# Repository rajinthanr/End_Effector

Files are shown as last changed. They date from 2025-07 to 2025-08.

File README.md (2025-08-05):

# Reconfigurable End Effector for Robotic Depalletizing



This repository documents the design and development of a flexible robotic end effector system, engineered to automate depalletizing operations in supermarket warehouses. The design emphasizes inclusive design principles, sensor-driven adaptability, and seamless mechanical-electronic integration.

---

## 📁 Table of Contents
1. [Project Overview](#project-overview)  
2. [Inclusive Design Framework](#inclusive-design-framework)  
3. [Market Research & Reference Design](#market-research--reference-design)  
4. [Conceptual Development](#conceptual-development)  
5. [Component Selection](#component-selection)  
6. [Mechanical Design](#mechanical-design)  
7. [Electronic Design](#electronic-design)  
8. [Firmware Development](#firmware-development)  
9. [Project Files](#project-files)  
10. [Team Members](#team-members)

---

## 🧠 Project Overview

This project aims to develop a **reconfigurable robotic end effector** capable of handling various box sizes and weights using vacuum-based gripping and pneumatic actuation. Key technologies include:

- **Time-of-Flight (ToF) sensors** for angular alignment  
- **Vacuum suction cups** for box lifting  
- **Pneumatic cylinders** for stabilization  
- **ATmega2560-based controller** with real-time firmware  

The end effector is compatible with standard robotic arms and designed for integration into warehouse logistics systems.

---

## 🌟 Inclusive Design Framework

We initiated this project using the [**Inclusive Design Toolkit**](https://www.inclusivedesigntoolkit.com/) by the University of Cambridge.

### 👥 Stakeholder Mapping
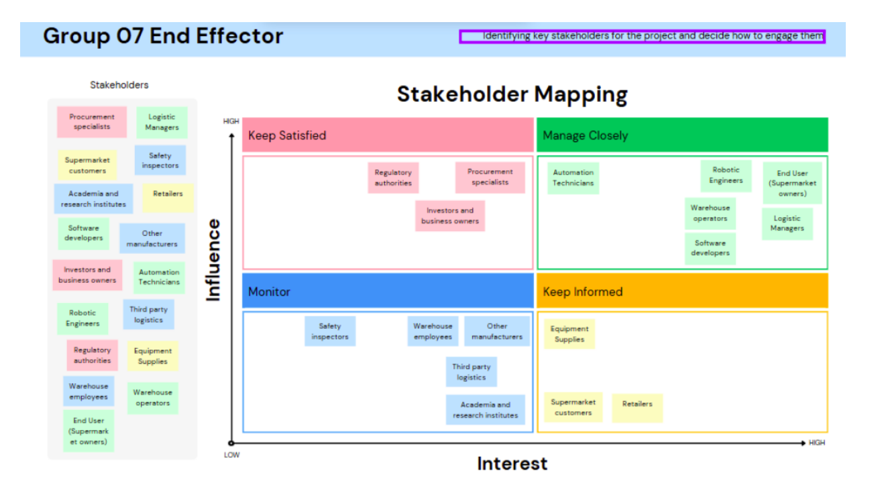
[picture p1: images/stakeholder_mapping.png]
Stakeholder Mapping


We categorized stakeholders into groups based on interest and influence to ensure inclusivity across the design lifecycle.

### 📌 User Needs Identified
- Automatic adaptation to box size and surface
- Safe handling of fragile or irregular packages
- Integration with existing robotic systems
- Minimal maintenance with reliable performance

---

## 🔍 Market Research & Reference Design

Before prototyping, we analyzed commercial solutions such as the **MCS-RP Gripper Series by WSR Solutions**, known for:
- Modular design
- High grip force
- Versatility in gripping geometry

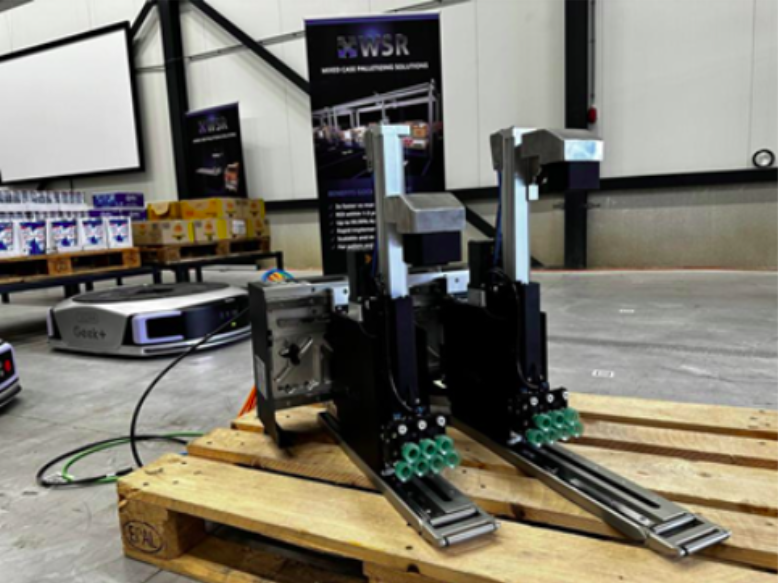
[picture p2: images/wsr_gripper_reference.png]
Reference Gripper


---

## ✍️ Conceptual Development

We iterated through several hand-drawn and CAD-based sketches to derive the optimal design.

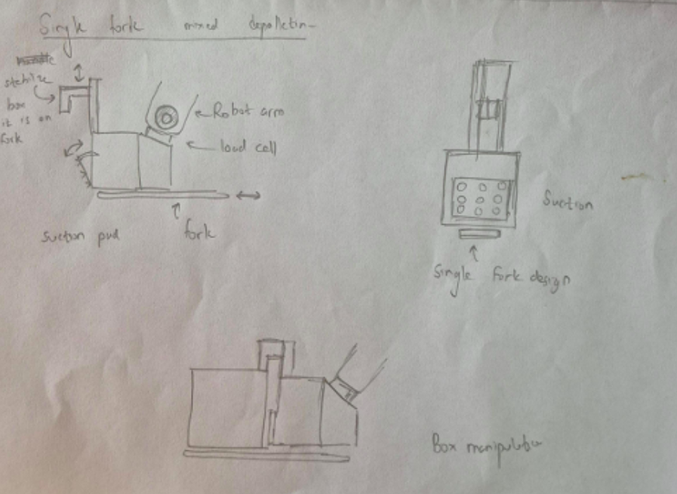
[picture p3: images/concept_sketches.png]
Conceptual Designs

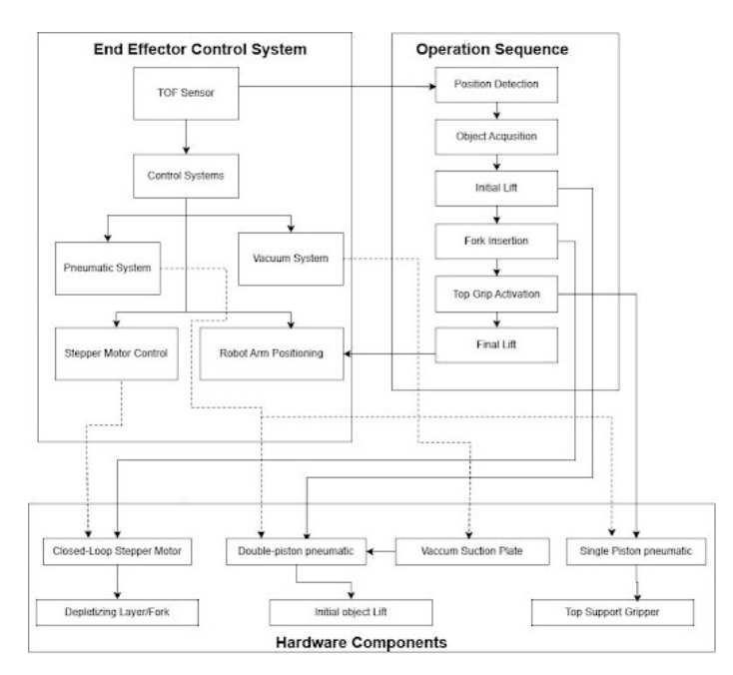
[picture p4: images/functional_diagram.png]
Functional_diagram


This included a **functional block diagram** illustrating the interaction between suction mechanisms, ToF sensors, solenoids, and microcontroller units.

---

## 🧹 Component Selection

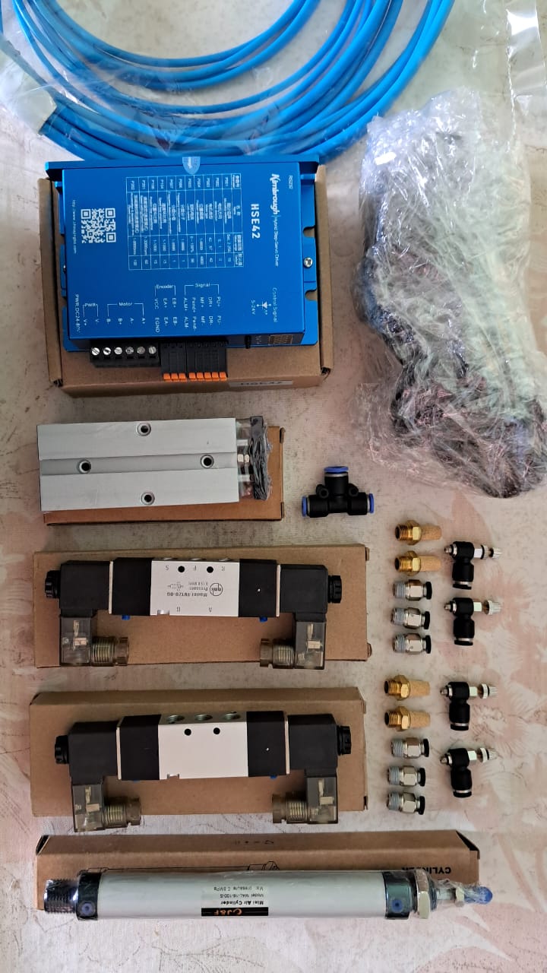
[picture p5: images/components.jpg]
Mechanical components


We conducted technical evaluations and cost analysis to select the following:

| Component | Model/Type | Reason |
|---|---|---|
| Stepper Motor | 42HSE47 Closed-loop | Precision & torque control |
| Pneumatic Cylinders | Airtac TN10X50 / MAL16X100 | Compact & cost-effective |
| Suction Cups | Schmalz FSG 20 NBE-ESD  | Adaptability to uneven surfaces |
| Vacuum Ejector | Airbest AZH10BS | Cost-efficient vacuum generation|
| Microcontroller | ATmega2560 | Multi-UART, reliable processing |

For more details about Tof sensor
https://support.nooploop.com/tofsense/protocol/

---

## 🛠️ Mechanical Design

### SolidWorks Iterations:
1. **First iteration**: Focused on confirming dimensions and fit.
2. **Final enclosure**: Zinc-coated sheet metal for durability and optimized integration with electronics.

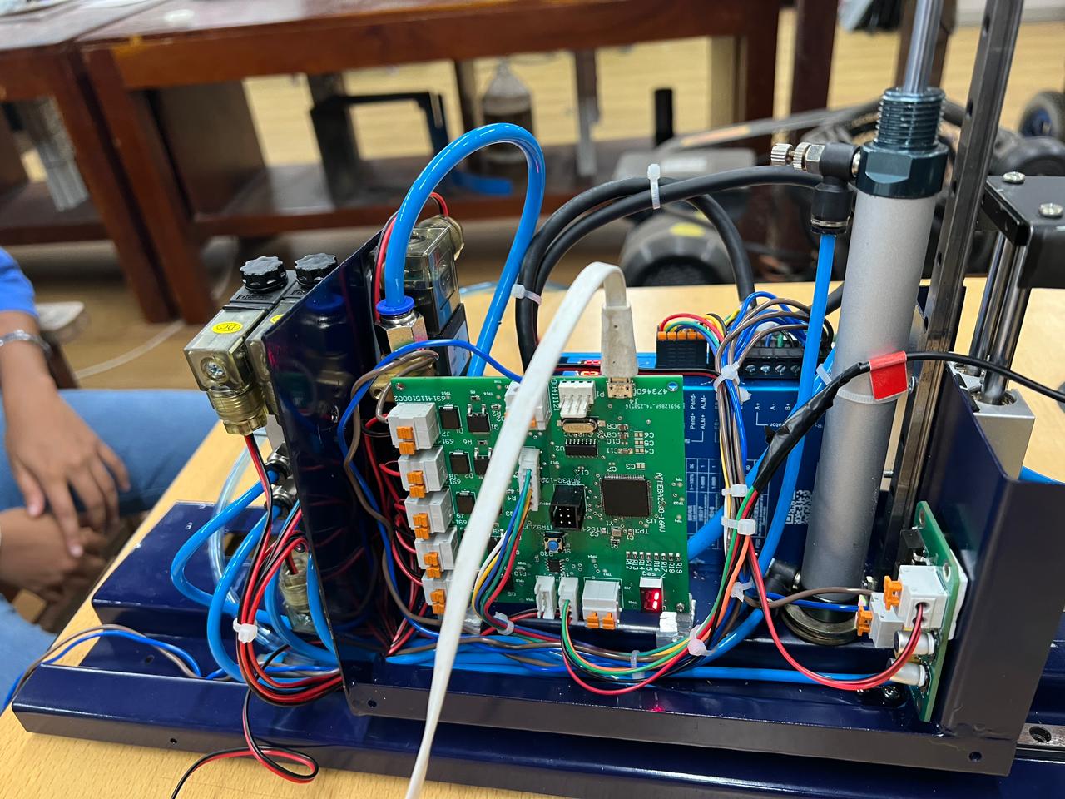
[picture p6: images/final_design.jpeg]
Final Mechanical Design


---

## 🔌 Electronic Design

We designed a **hierarchical schematic** in Altium Designer and manufactured the PCBs via JLCPCB.

### 📀 PCB Highlights:
- 2-layer main control PCB  
- Separate buck converter PCB for power regulation  
- RS485, UART, and SPI interfaces  
- Solenoid switching circuitry with flyback protection

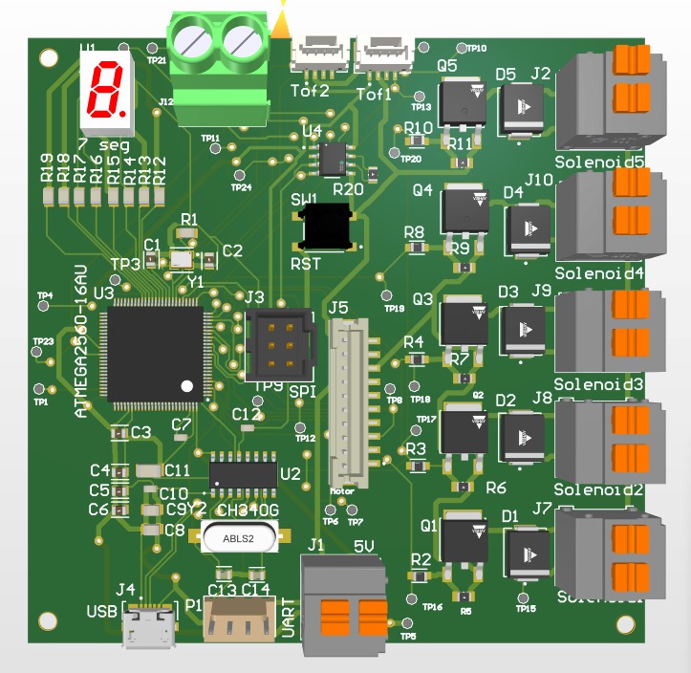
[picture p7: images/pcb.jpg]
PCB


> ⚙️ PCB and schematic files are included in the `/hardware` directory.

---

## 💻 Firmware Development

The firmware was developed using **Atmel Studio** and **register-level programming** for ATmega2560. Key features include:

- Multi-UART communication with ToF sensors
- Real-time control of vacuum, solenoids, and motors
- Serial communication with host controller (RS485)
- Modular codebase with functional headers and drivers

> Firmware source can be found under the `/firmware` folder.

---

## 📂 Project Files

| Folder | Description |
|---|---|
| `/firmware` | Register-level code for ATmega2560 |
| `/hardware` | Altium schematics, PCB, and BOM |
| `/cad` | SolidWorks files and STL exports |
| `/images` | Diagrams and renders used in this repository |
| `/docs` | Full project report and datasheets |

---

## 👨‍💻 Team Members

- Muftee M. M. M.  
- Goonetilleke P.  
- Jayakody J. A. K.  
- Rajinthan R.
- Warushavithana N. D.  
- Praveen V. V. J.  
- V. G. V. Gunasekara  

---

## 📜 License

This project is licensed under the MIT License – see the [LICENSE](LICENSE) file for details.

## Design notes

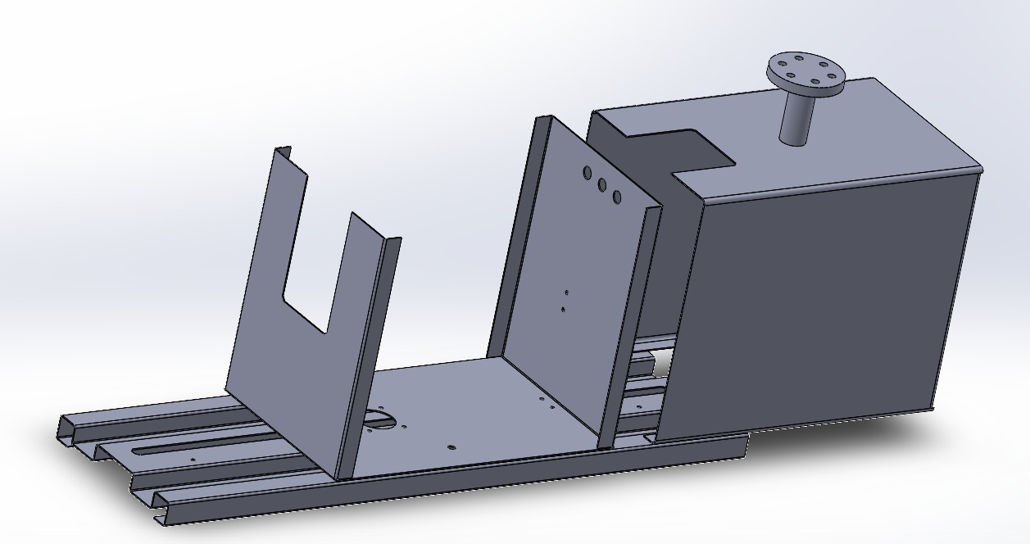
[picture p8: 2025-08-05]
images/enclosure.jpg

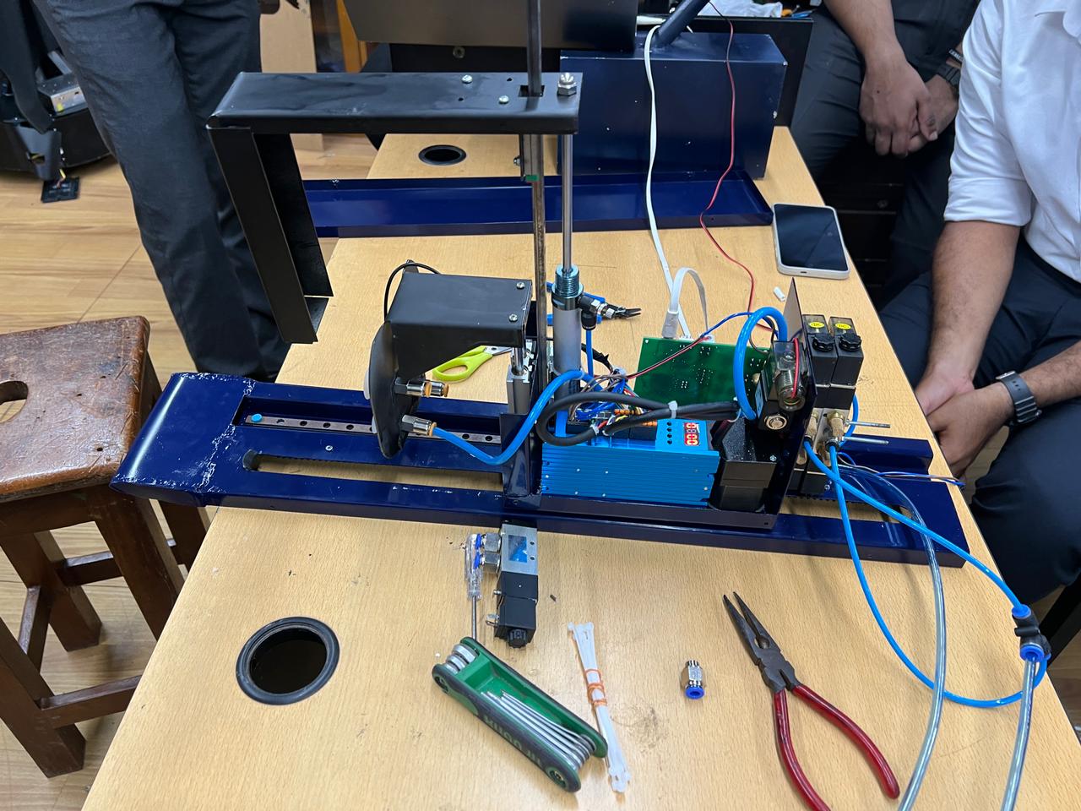
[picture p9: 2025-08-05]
images/end_effector.jpeg

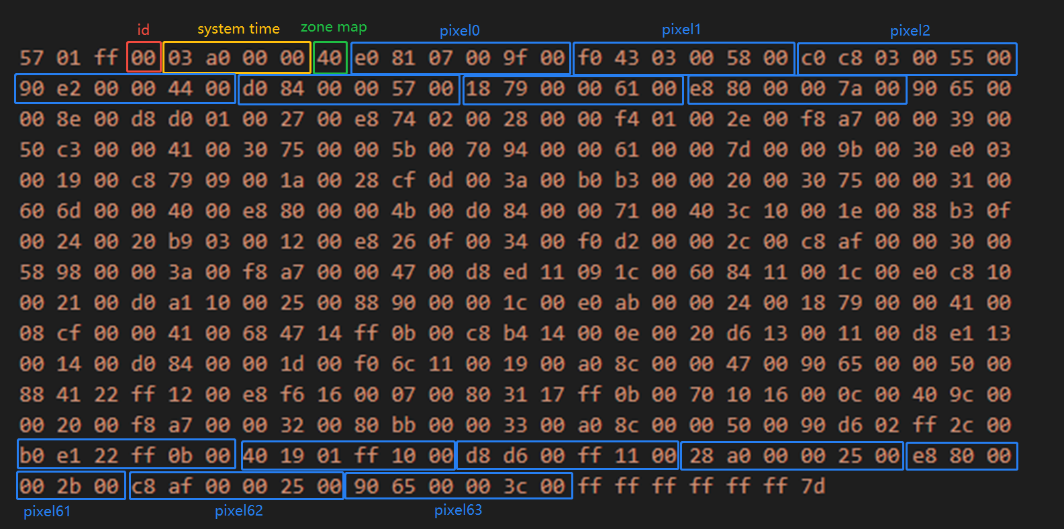
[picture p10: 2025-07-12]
firmware/TOFSense_M_unpack_demo.png

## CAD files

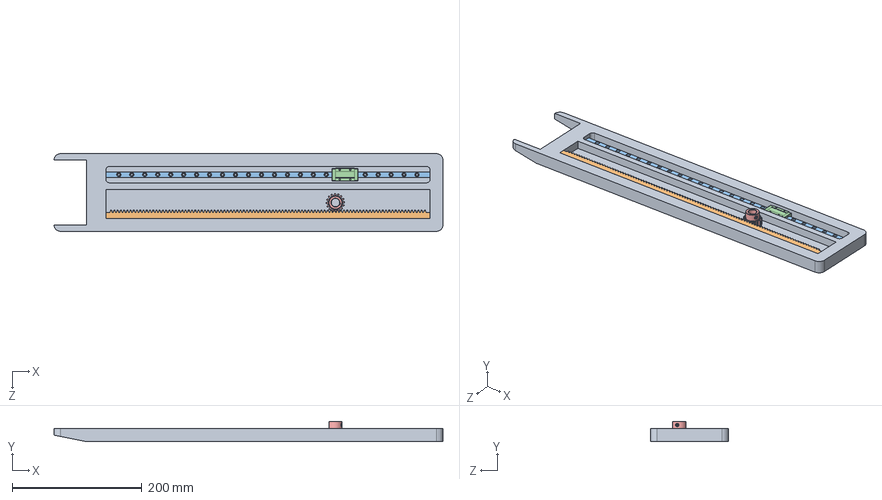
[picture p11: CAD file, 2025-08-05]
cad/Assembly.SLDASM
600.0 x 31.1 x 120.0 mm
fork
Rack
MGNR09_xxx
MGN09H

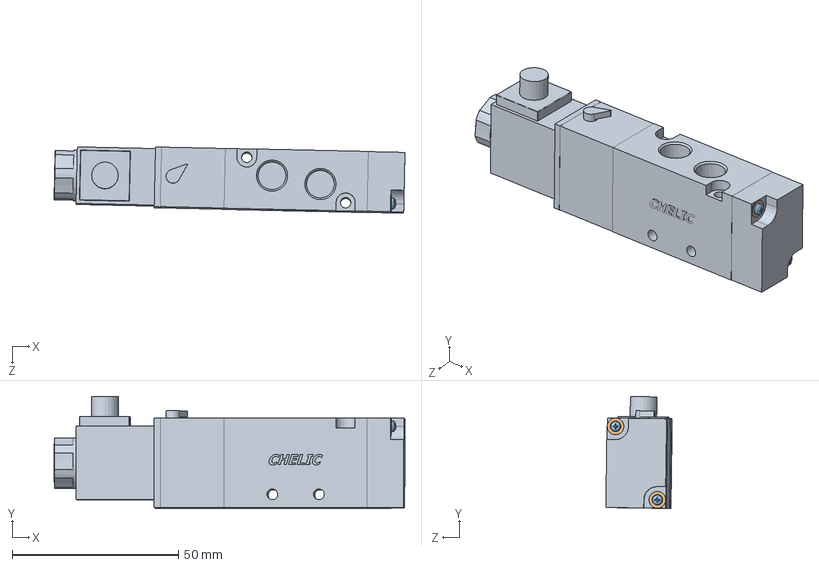
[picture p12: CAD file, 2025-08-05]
cad/Solenoid valve 52-18 Chelic.stp.SLDASM
105.5 x 33.7 x 20.0 mm
Solenoid valve 52-18 Chelic.stp
ISO 7091 - ST 2 - 100 HV.stp x 2
ISO 7045 - M1,6 x 3 - 4.8 - Z.stp x 2

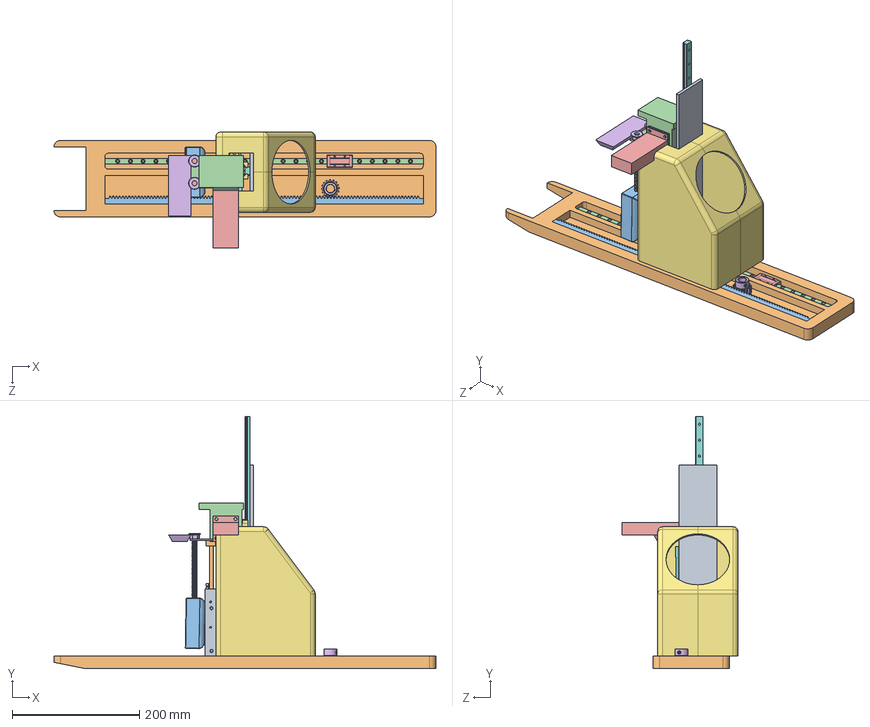
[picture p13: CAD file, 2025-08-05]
cad/vaccum-assembly.SLDASM
600.0 x 396.4 x 182.1 mm
CXSM10-50_cyl_cxs
CXSM10-50_pr_cxs
initial_enclosure
connector
rod x 2
nut x 2
161268 DZF-32-100-A-P-A---(ZR)
DIN-439-B - M10x1.25(F)
332223 DGP-25 x 2
161268 DZF-32-100-A-P-A---(KS)
main
arm_ex^Assem1
rubber
mov
rail
base
fork
Rack
MGNR09_xxx
MGN09H

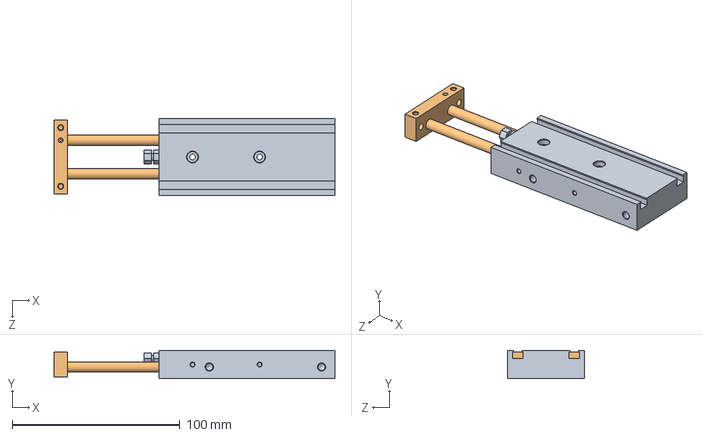
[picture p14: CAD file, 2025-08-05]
cad/5cmm pnum.SLDASM
167.6 x 17.0 x 46.0 mm
CXSM10-50_cyl_cxs
CXSM10-50_pr_cxs

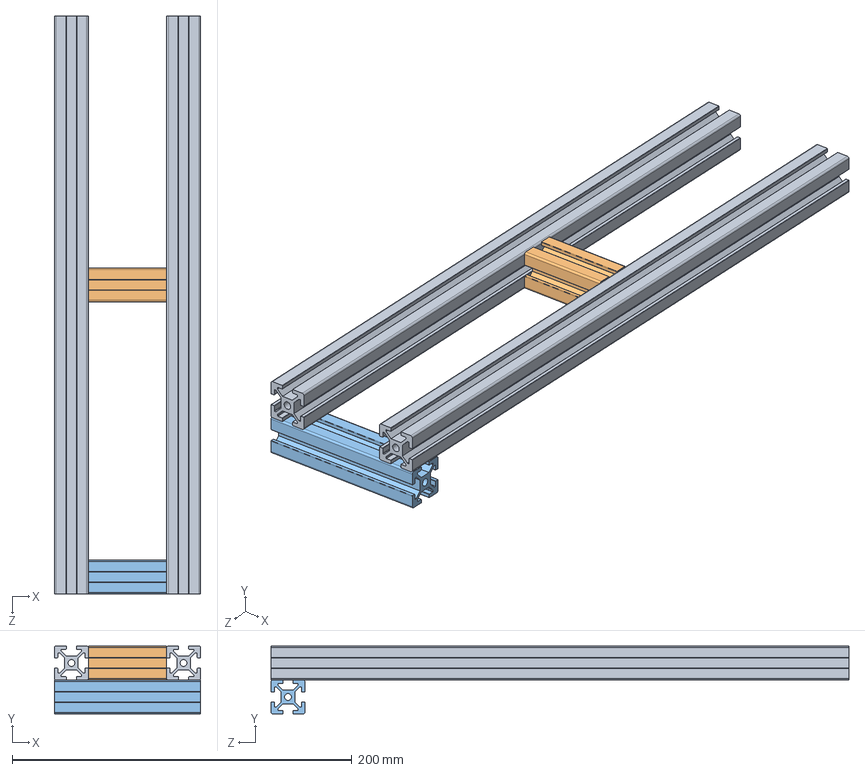
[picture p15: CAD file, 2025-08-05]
cad/Frame.SLDASM
86.0 x 40.0 x 340.0 mm
T slot 30 x 2
T slot hor 4c6
T slot hor 8c6

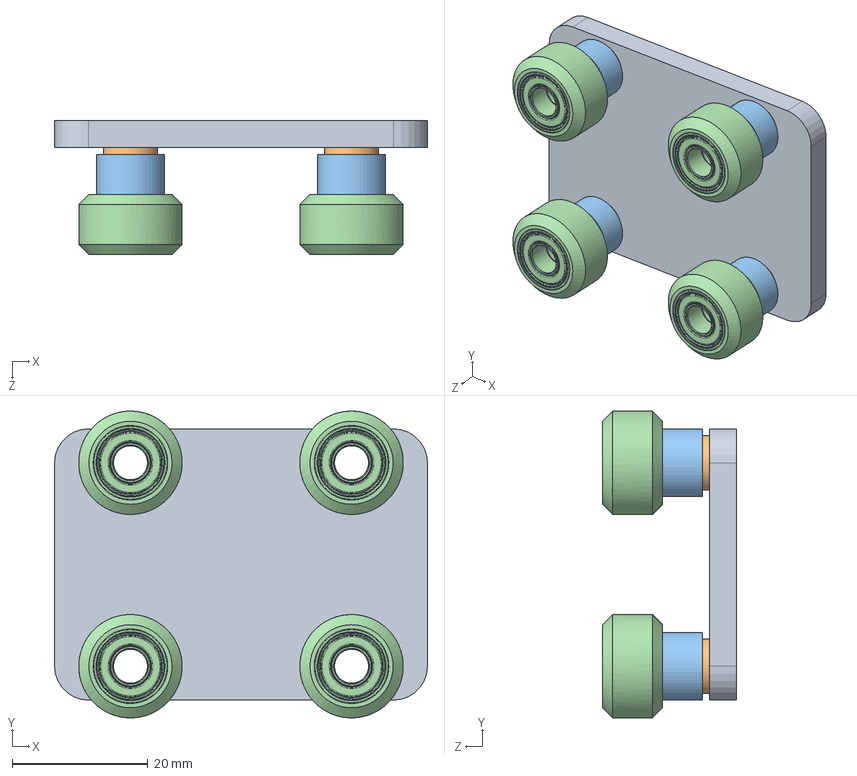
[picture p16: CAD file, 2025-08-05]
cad/vwheels.SLDASM
55.0 x 45.2 x 19.8 mm
spacer
MVG-P2 x 4
MVG-P3 x 4
MVG-P7 x 4

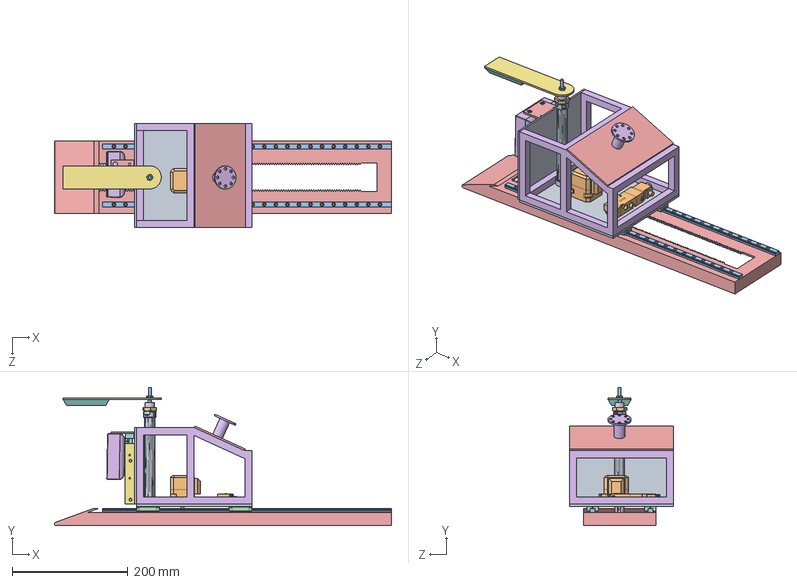
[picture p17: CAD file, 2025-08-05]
cad/Final.SLDASM
582.7 x 239.0 x 180.0 mm
botom plate
17HS08 stepper
MGNR09_xxx x 2
MGN09H x 4
rail plate
top box
CXSM10-50_cyl_cxs
CXSM10-50_pr_cxs
16 X 100 Cylinder bore
Nut 16
Rod
Nut 5
connector
initial_enclosure
top grpi stand
rubber
front cover
Solenoid valve 52-18 Chelic.stp
ISO 7091 - ST 2 - 100 HV.stp x 2
ISO 7045 - M1,6 x 3 - 4.8 - Z.stp x 2
top cover
arm connector circle

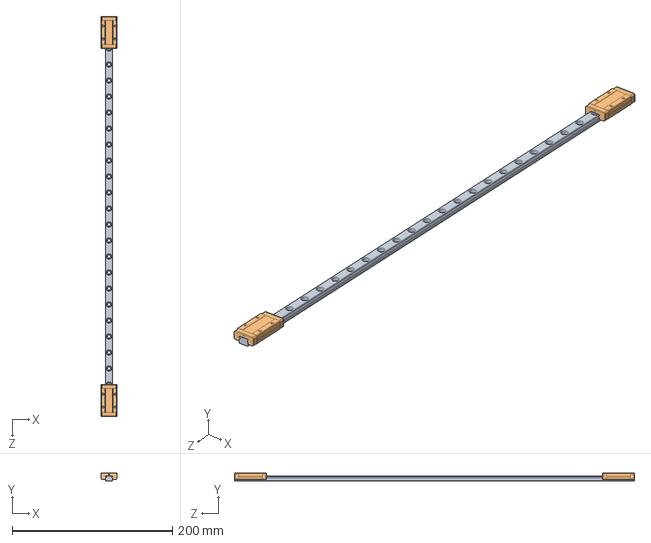
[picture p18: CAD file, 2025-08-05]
cad/MGN09.SLDASM
20.0 x 10.0 x 500.0 mm
MGNR09_xxx
MGN09H x 2

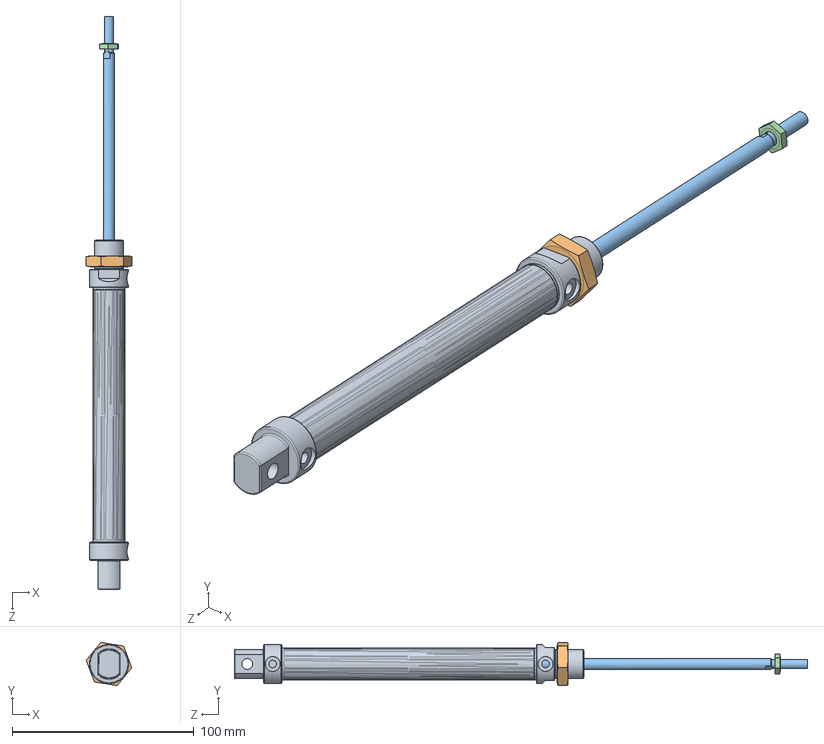
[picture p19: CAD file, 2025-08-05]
cad/16 X 100 Cylinder.SLDASM
25.1 x 23.8 x 315.0 mm
16 X 100 Cylinder bore
Nut 16
Rod
Nut 5

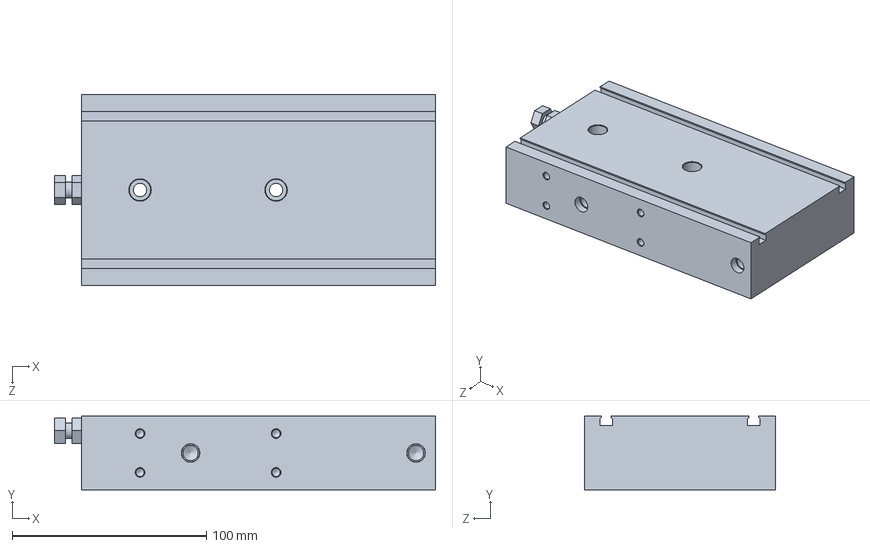
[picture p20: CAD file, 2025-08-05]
cad/CXSM10-50_cyl_cxs.sldprt
196.0 x 38.0 x 98.0 mm

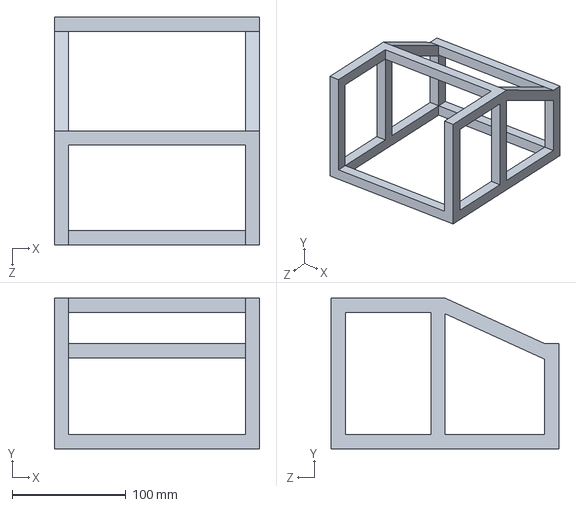
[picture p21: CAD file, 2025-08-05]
cad/top box.SLDPRT
180.0 x 132.5 x 200.0 mm

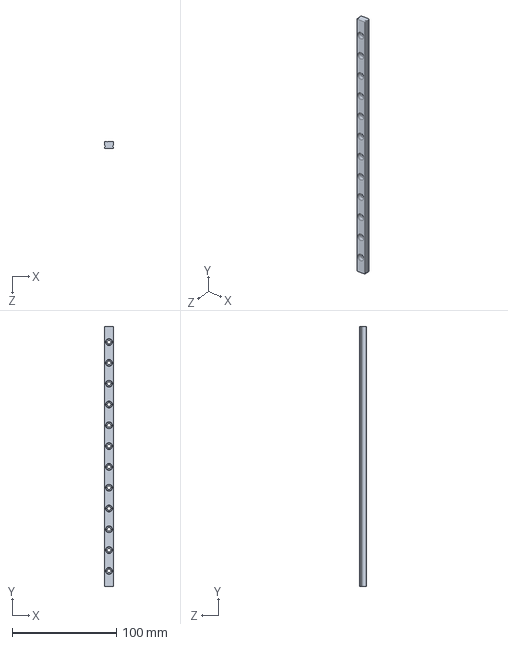
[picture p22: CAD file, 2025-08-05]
cad/MGNR09_xxx.SLDPRT
9.00 x 250.0 x 6.50 mm

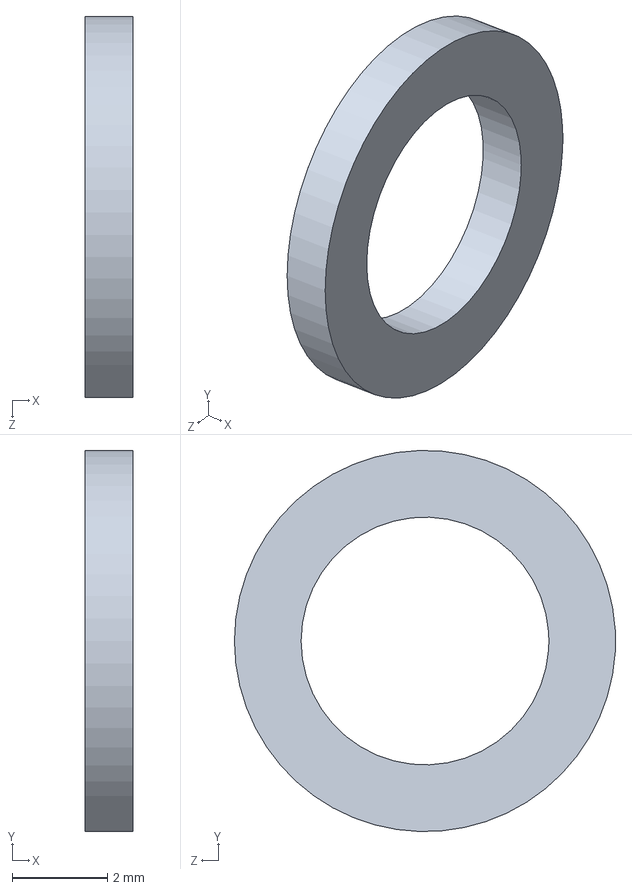
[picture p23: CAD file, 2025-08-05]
cad/MVG-P2.SLDPRT
1.00 x 8.00 x 8.00 mm

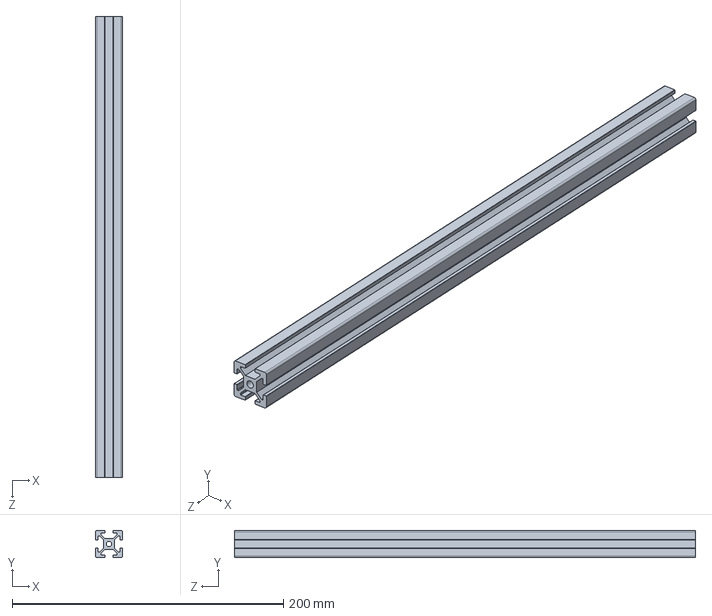
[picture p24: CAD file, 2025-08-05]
cad/T slot 30.SLDPRT
20.0 x 20.0 x 340.0 mm

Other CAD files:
cad/Rod.SLDPRT
cad/Gear.SLDPRT
cad/17HS08 stepper.SLDPRT
cad/top cover.SLDPRT
cad/16 X 100 Cylinder bore.SLDPRT
cad/161268 DZF-32-100-A-P-A---(0).SLDASM
cad/161268 DZF-32-100-A-P-A---(KS).SLDPRT
cad/161268 DZF-32-100-A-P-A---(ZR).SLDPRT
cad/332223 DGP-25.SLDPRT
cad/CXSM10-50_pr_cxs.sldprt
cad/DIN-439-B - M10x1.25(F).SLDPRT
cad/ISO 7045 - M1,6 x 3 - 4.8 - Z.stp.SLDPRT
cad/ISO 7091 - ST 2 - 100 HV.stp.SLDPRT
cad/MGN09H.SLDPRT
cad/MVG-P3.SLDPRT
cad/MVG-P7.SLDPRT
cad/Nut 16.SLDPRT
cad/Nut 5.SLDPRT
cad/Rack.SLDPRT
cad/Solenoid valve 52-18 Chelic.stp.SLDPRT
cad/T slot hor 4c6.SLDPRT
cad/T slot hor 8c6.SLDPRT
cad/arm connector circle.SLDPRT
cad/arm connector.SLDPRT
cad/botom plate.SLDPRT
cad/connector.SLDPRT
cad/fork.SLDPRT
cad/front cover.SLDPRT
cad/rail plate.SLDPRT
cad/rubber.SLDPRT
cad/spacer.SLDPRT
cad/top grpi stand.SLDPRT
cad/top hand.SLDPRT

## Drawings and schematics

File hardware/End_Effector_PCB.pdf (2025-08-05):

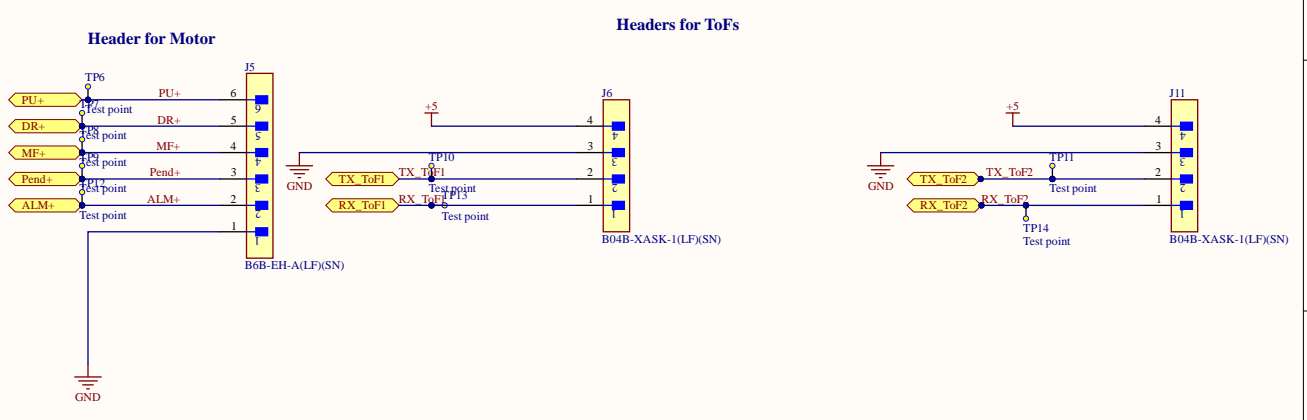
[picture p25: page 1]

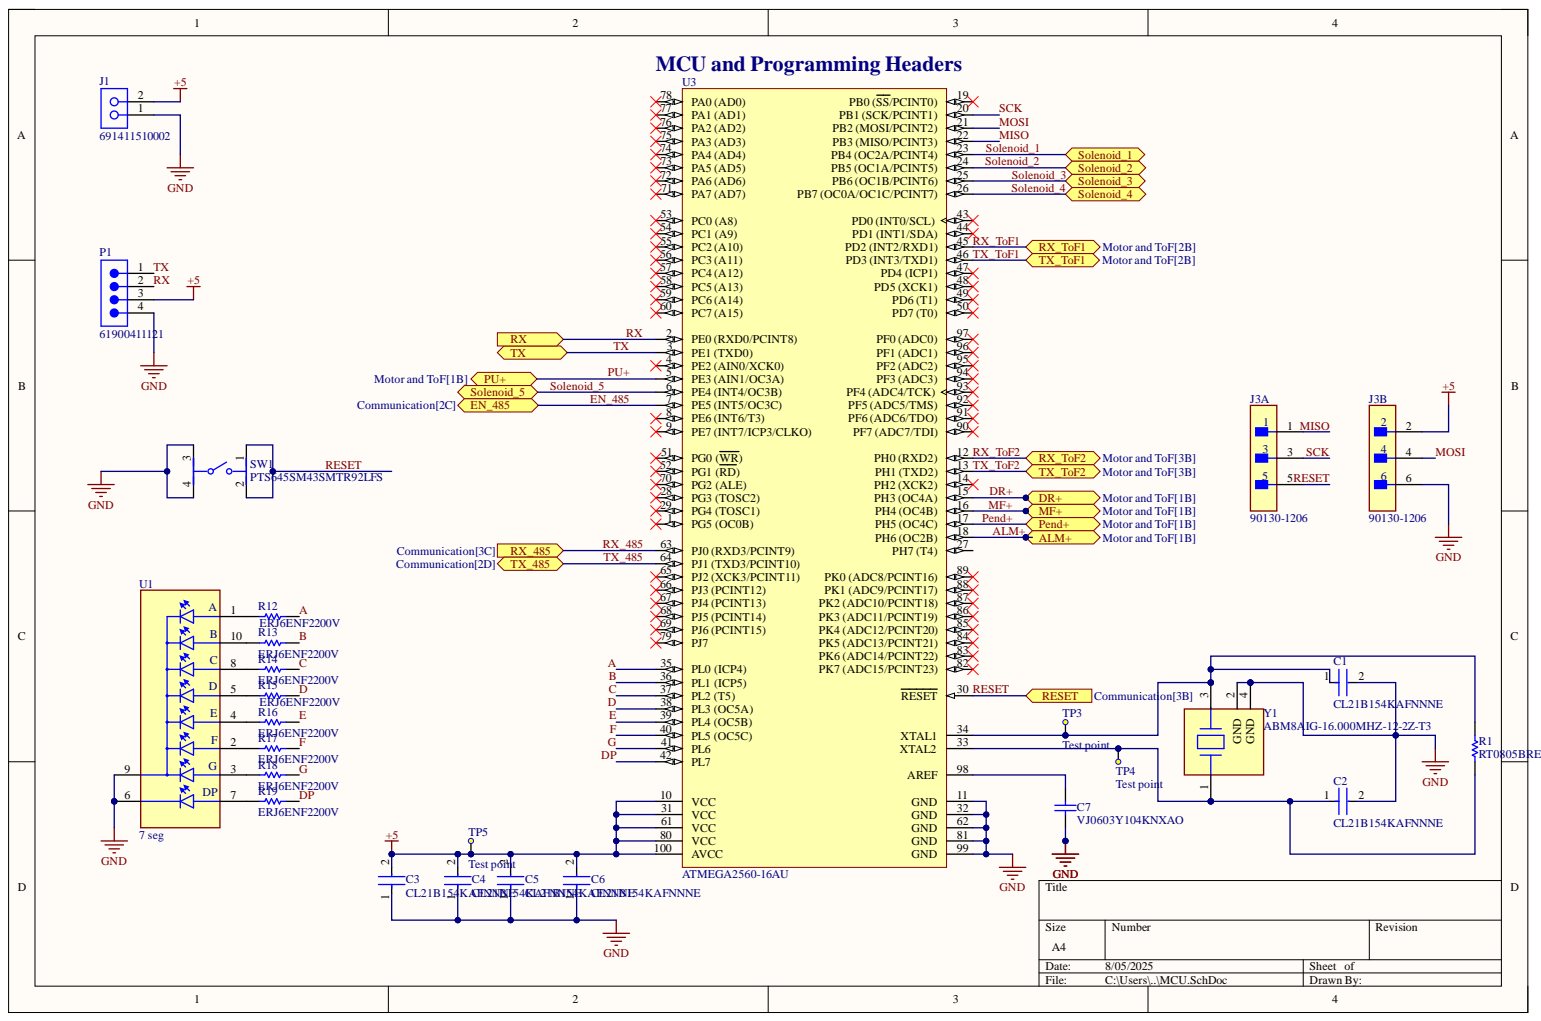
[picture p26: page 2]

3 1 | 3 2 | 2 1B1 5 4 K
6 1 | 6 2
8 0 | 8 1
1 0 0 | 9 9

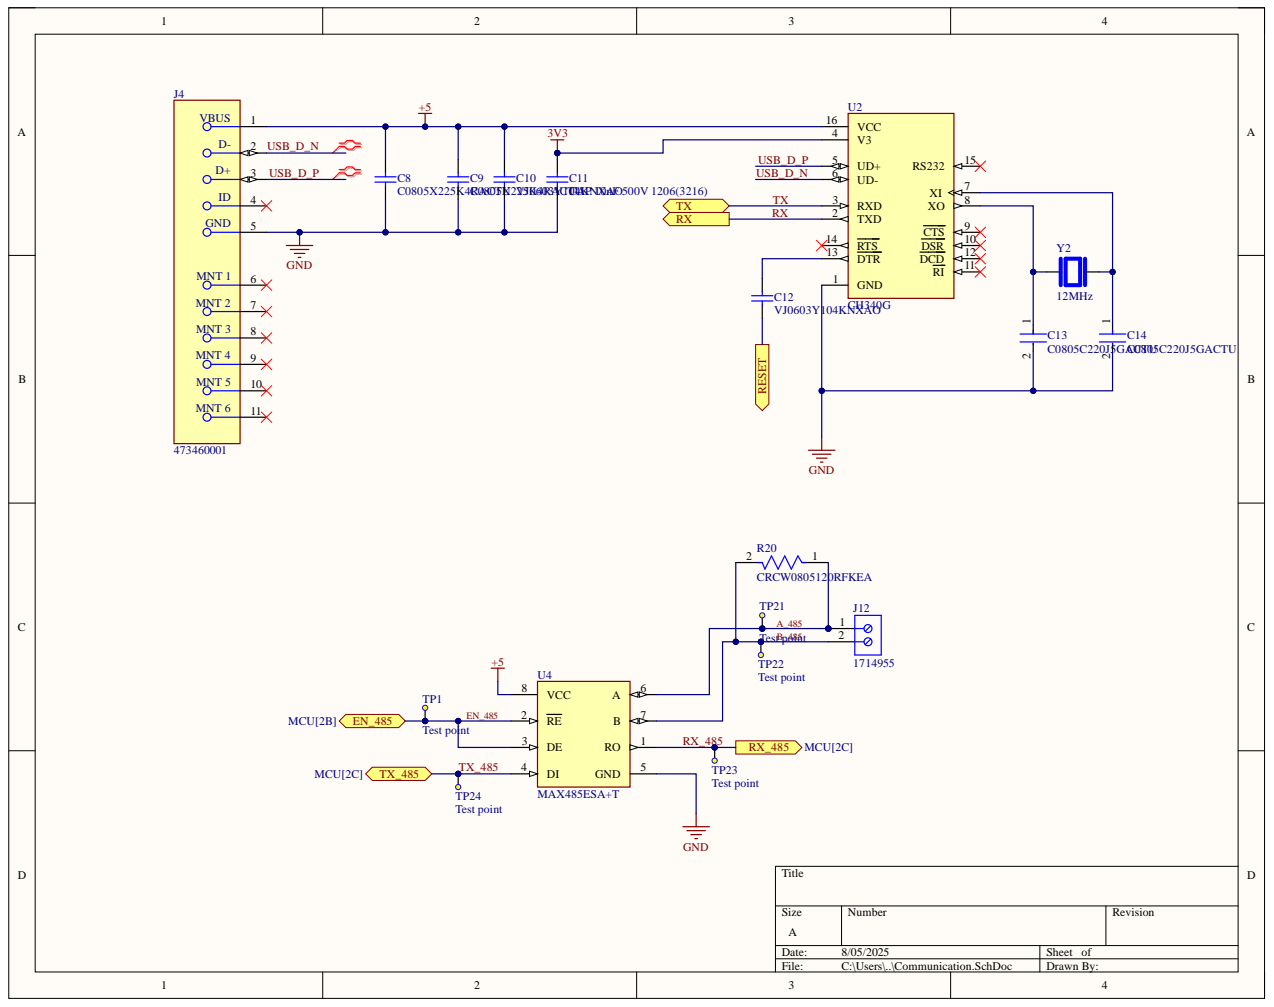
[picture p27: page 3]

Size A | Number | Revision

Date: 8/05/2025 | Sheet of
File: C:\Users\..\Communication.SchDoc | Drawn By:

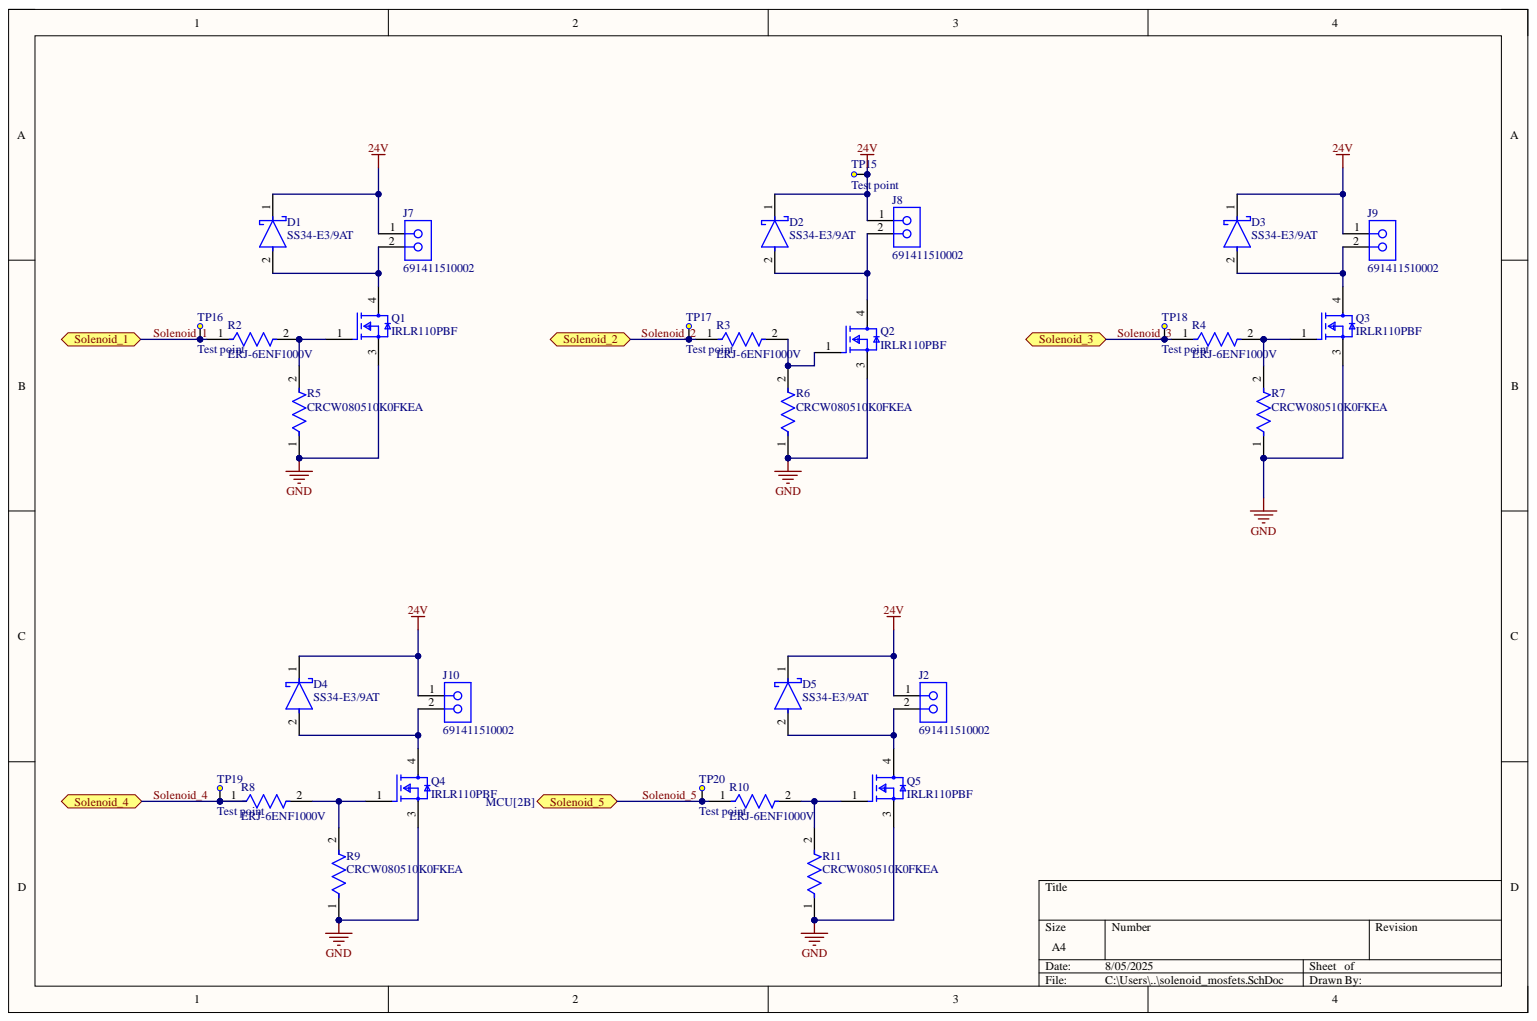
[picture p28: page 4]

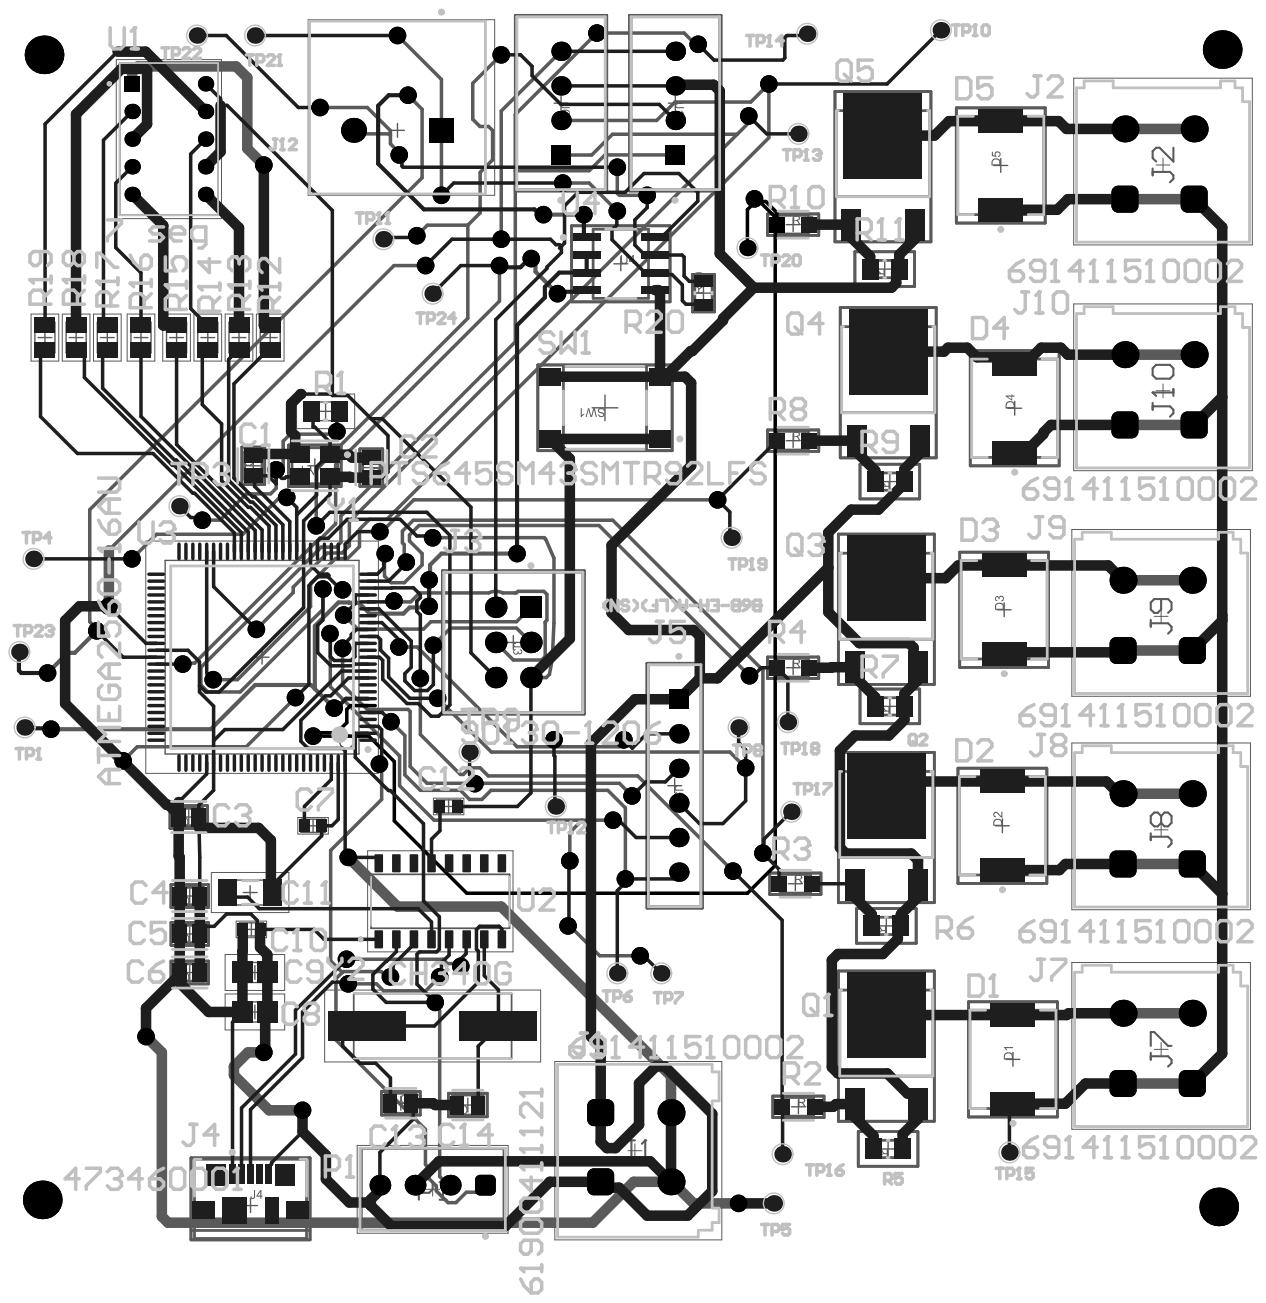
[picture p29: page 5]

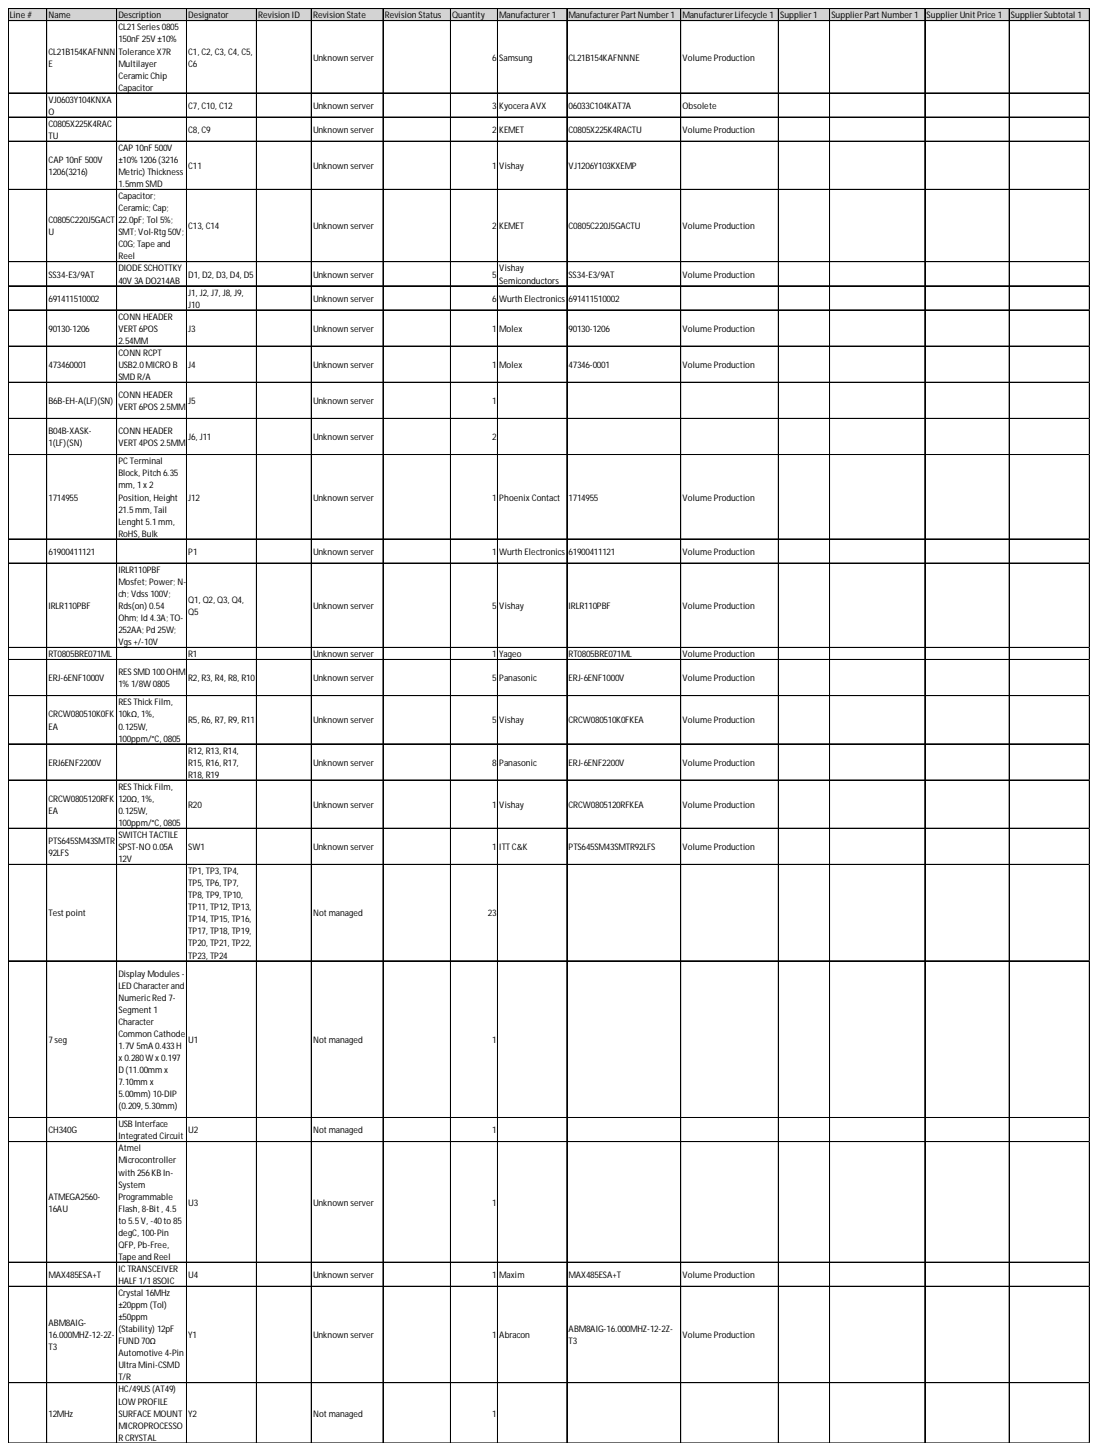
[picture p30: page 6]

Line # | Name | Description | Designator | Revision ID | Revision State | Revision Status | Quantity | Manufacturer 1 | Manufacturer Part Number 1 | Manufacturer Lifecycle 1 | Supplier 1 | Supplier Part Number 1 | Supplier Unit Price 1 | Supplier Subtotal 1

CL21B154KAFNNN E | CL21 Series 0805 150nF 25V ±10% Tolerance X7R Multilayer Ceramic Chip Capacitor | C1, C2, C3, C4, C5, C6 | | Unknown server | | | 6 Samsung | CL21B154KAFNNNE | Volume Production

VJ0603Y104KNXA O | | C7, C10, C12 | | Unknown server | | | 3 Kyocera AVX | 06033C104KAT7A | Obsolete

C0805X225K4RAC TU | | C8, C9 | | Unknown server | | | 2 KEMET | C0805X225K4RACTU | Volume Production

CAP 10nF 500V 1206(3216) | CAP 10nF 500V ±10% 1206 (3216 Metric) Thickness 1.5mm SMD | C11 | | Unknown server | | | 1 Vishay | VJ1206Y103KXEMP

C0805C220J5GACT U | Capacitor; Ceramic; Cap; 22.0pF; Tol 5%; SMT; Vol-Rtg 50V; C0G; Tape and Reel | C13, C14 | | Unknown server | | | 2 KEMET | C0805C220J5GACTU | Volume Production

SS34-E3/9AT | DIODE SCHOTTKY 40V 3A DO214AB | D1, D2, D3, D4, D5 | | Unknown server | | | 5 Vishay Semiconductors | SS34-E3/9AT | Volume Production

691411510002 | | J1, J2, J7, J8, J9, J10 | | Unknown server | | | 6 Wurth Electronics 691411510002

90130-1206 | CONN HEADER VERT 6POS 2.54MM | J3 | | Unknown server | | | 1 Molex | 90130-1206 | Volume Production

473460001 | CONN RCPT USB2.0 MICRO B SMD R/A | J4 | | Unknown server | | | 1 Molex | 47346-0001 | Volume Production

B6B-EH-A(LF)(SN) | CONN HEADER VERT 6POS 2.5MM J5 | | | Unknown server | | | 1

B04B-XASK-1(LF)(SN) | CONN HEADER VERT 4POS 2.5MM J6, J11 | | | Unknown server | | | 2

1714955 | PC Terminal Block, Pitch 6.35 mm, 1 x 2 Position, Height 21.5mm, Tail Lenght 5.1mm, RoHS, Bulk | J12 | | Unknown server | | | 1 Phoenix Contact | 1714955 | Volume Production

61900411121 | | P1 | | Unknown server | | | 1 Wurth Electronics 61900411121 | | Volume Production

IRLR110PBF | IRLR110PBF Mosfet; Power; N-ch; Vdss 100V; Rds(on) 0.54 Ohm; Id 4.3A; TO-252AA; Pd 25W; Vgs +/-10V | Q1, Q2, Q3, Q4, Q5 | | Unknown server | | | 5 Vishay | IRLR110PBF | Volume Production

RT0805BRE071ML | | R1 | | Unknown server | | | 1 Yageo | RT0805BRE071ML | Volume Production

ERJ-6ENF1000V | RES SMD 100OHM 1% 1/8W 0805 | R2, R3, R4, R8, R10 | | Unknown server | | | 5 Panasonic | ERJ-6ENF1000V | Volume Production

CRCW080510K0FK EA | RES Thick Film, 10kΩ, 1%, 0.125W, 100ppm/°C, 0805 | R5, R6, R7, R9, R11 | | Unknown server | | | 5 Vishay | CRCW080510K0FKEA | Volume Production

ERJ6ENF2200V | | R12, R13, R14, R15, R16, R17, R18, R19 | | Unknown server | | | 8 Panasonic | ERJ-6ENF2200V | Volume Production

CRCW0805120RFK EA | RES Thick Film, 120Ω, 1%, 0.125W, 100ppm/°C, 0805 | R20 | | Unknown server | | | 1 Vishay | CRCW0805120RFKEA | Volume Production

PTS645SM43SMTR 92LFS | SWITCH TACTILE SPST-NO 0.05A 12V | SW1 | | Unknown server | | | 1 ITT C&K | PTS645SM43SMTR92LFS | Volume Production

Test point | | TP1, TP3, TP4, TP5, TP6, TP7, TP8, TP9, TP10, TP11, TP12, TP13, TP14, TP15, TP16, TP17, TP18, TP19, TP20, TP21, TP22, TP23, TP24 | | Not managed | | 23

7 seg | Display Modules -LED Character and Numeric Red 7-Segment 1 Character Common Cathode 1.7V 5mA 0.433 H x 0.280 W x 0.197 D (11.00mm x 7.10mm x 5.00mm) 10-DIP (0.209, 5.30mm) | U1 | | Not managed | | | 1

CH340G | USB Interface Integrated Circuit | U2 | | Not managed | | | 1

ATMEGA2560-16AU | Atmel Microcontroller with 256 KB In-System Programmable Flash, 8-Bit , 4.5 to 5.5 V, -40 to 85 degC, 100-Pin QFP, Pb-Free, Tape and Reel | U3 | | Unknown server | | | 1

MAX485ESA+T | IC TRANSCEIVER HALF 1/1 8SOIC | U4 | | Unknown server | | | 1 Maxim | MAX485ESA+T | Volume Production

ABM8AIG-16.000MHZ-12-2Z-T3 | Crystal 16MHz ±20ppm (Tol) ±50ppm (Stability) 12pF FUND 70Ω Automotive 4-Pin Ultra Mini-CSMD T/R | Y1 | | Unknown server | | | 1 Abracon | ABM8AIG-16.000MHZ-12-2Z-T3 | Volume Production

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

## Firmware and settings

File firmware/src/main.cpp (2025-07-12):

#include "main.h"
#include "TofSensor.h"
#include "peripherals.h"
#include "fork.h"
#include "pneumatics.h"
#include "functions.h"
#include "millis.h"

UART uart3(&UBRR0H, &UBRR0L, &UCSR0A, &UCSR0B, &UCSR0C, &UDR0);
UART uart1(&UBRR1H, &UBRR1L, &UCSR1A, &UCSR1B, &UCSR1C, &UDR1);

UART uart0(&UBRR3H, &UBRR3L, &UCSR3A, &UCSR3B, &UCSR3C, &UDR3, PORTE, PORTE5);

int main()
{
  millis_init();
  uart0.init();
  uart3.init();
  setup_seven_segment();

  seven_segment(3);

  uart0.transmit("Booting...\n");
  init_pneumatics();
  tof_init();
  init_fork();
  uart0.transmit("End Effector Ready\n");

  uart3.transmit("UART3 Initialized\n");

  seven_segment(1);

  while (1)
  {
    //read_tof();
    //_delay_ms(10);
    char command[64] = {0};
    if (uart0.receive_line(command, sizeof(command)))
    {
      process_command(command);
    }
  }
}

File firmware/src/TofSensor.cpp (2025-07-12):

#include <math.h>
#include "TofSensor.h"
#include "uart.h"

extern UART uart0;
extern UART uart1;

uint8_t queryCommand[8] = {0x57, 0x10, 0xFF, 0xFF, 0x03, 0xFF, 0xFF, 0x66};
uint8_t frame[FRAME_SIZE];
float distances[4];


constexpr float DEG2RAD = 3.14159265 / 180.0;


constexpr float H_FOV_DEG = 45.0;
constexpr float V_FOV_DEG = 45.0;


void tof_init()
{
    uart1.init(); // Initialize UART1
}

void read_tof()
{
    uart0.transmit("\n\n");

    sendQuery(); // Send the query command to the sensor
    
    // Wait for header
    while (true)
    {
        if (uart1.read() == HEADER_BYTE_0)
        {
            uart1.read(); 
            break;
        }
    }
    

    // Read the rest of the frame (FRAME_SIZE - 2 already read)
    int bytesRead = 0;
    while (bytesRead < FRAME_SIZE - 2)
    {
        if(uart1.available())
        {
            frame[bytesRead++] = uart1.read();
        }
    }
    //uart0.transmit("Frame received\n");

    // Parse and print corner distances 
    int dataStart = 7; 
    int distances_index = 0;
    for (int i = 0; i < DATA_POINTS; i++)
    {
        int offset = dataStart + i * POINT_SIZE;
        if (offset + 2 >= FRAME_SIZE)
            break;

        float distance = calculateValue(frame[offset], frame[offset + 1], frame[offset + 2]);

        // Only print four corners
        //if (i == 35 || i == 36 || i == 43 || i == 44)
        if (i == 0 || i == 7 || i == 56 || i == 63)
        {
            printDistance(i, distance);
            distances[distances_index] = distance;
            distances_index++;
        }
    }

    calculateAngleFromCorners(distances[0], distances[1], distances[2], distances[3]);

    //_delay_ms(2000); 
}







float calculateAngleFromCorners(float d0, float d7, float d56, float d63)
{
    // Pixel grid positions for the 4 corners
    int x0 = 0, y0 = 0;
    int x7 = 7, y7 = 0;
    int x56 = 0, y56 = 7;
    int x63 = 7, y63 = 7;

    // Angle per pixel
    float hAnglePerPixel = H_FOV_DEG / 7.0;
    float vAnglePerPixel = V_FOV_DEG / 7.0;

    // Convert pixel positions to angles (centered at 0)
    float ax0 = (x0 - 3.5) * hAnglePerPixel;
    float ay0 = (y0 - 3.5) * vAnglePerPixel;
    float ax7 = (x7 - 3.5) * hAnglePerPixel;
    float ay7 = (y7 - 3.5) * vAnglePerPixel;
    float ax56 = (x56 - 3.5) * hAnglePerPixel;
    float ay56 = (y56 - 3.5) * vAnglePerPixel;
    float ax63 = (x63 - 3.5) * hAnglePerPixel;
    float ay63 = (y63 - 3.5) * vAnglePerPixel;

    // Convert to 3D coordinates
    float x_sum = d0 * tan(ax0 * DEG2RAD) +
                  d7 * tan(ax7 * DEG2RAD) +
                  d56 * tan(ax56 * DEG2RAD) +
                  d63 * tan(ax63 * DEG2RAD);

    float y_sum = d0 * tan(ay0 * DEG2RAD) +
                  d7 * tan(ay7 * DEG2RAD) +
                  d56 * tan(ay56 * DEG2RAD) +
                  d63 * tan(ay63 * DEG2RAD);

    float z_sum = d0 + d7 + d56 + d63;

    // Average to get direction vector
    float x_avg = x_sum / 4.0;
    float y_avg = y_sum / 4.0;
    float z_avg = z_sum / 4.0;

    // Compute angle from center in degrees
    float horizontalAngle = 10*atan2(x_avg, z_avg) * 180.0 / 3.14159265;
    float verticalAngle = 10*atan2(y_avg, z_avg) * 180.0 / 3.14159265;

    uart0.transmit("Horizontal Angle: ");
    uart0.transmit(horizontalAngle, 2);
    uart0.transmit(" Vertical Angle: ");
    uart0.transmit(verticalAngle, 2);
    uart0.transmit("\n");

   
    return horizontalAngle; 
}

// Parse int24 as per protocol: (b0 << 8 | b1 << 16 | b2 << 24) / 256
int32_t parse_int24(uint8_t b0, uint8_t b1, uint8_t b2)
{
    int32_t value = ((int32_t)b2 << 16) | ((int32_t)b1 << 8) | b0;
    // Sign extend if the top bit is set (for 24-bit signed)
    if (value & 0x800000)
        value |= 0xFF000000;
    return value;
}

float calculateValue(uint8_t b0, uint8_t b1, uint8_t b2)
{
    int32_t temp = parse_int24(b0, b1, b2);
    return temp / 1000.0; //mm 
}

void printDistance(int index, float raw)
{
    float mm = raw;
    uart0.transmit("Index ");
    uart0.transmit(" ");
    //uart0.transmit((float)index, 0);
    uart0.transmit(": ");
    uart0.transmit(mm, 3);
    uart0.transmit(" mm\n");
}

void sendQuery()
{
    uart1.transmit(queryCommand, 8);
}

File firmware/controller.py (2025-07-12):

import tkinter as tk
from tkinter import ttk
import serial

# Setup serial communication
SERIAL_PORT = 'COM9'  # Change to your port, e.g., 'COM4' or '/dev/ttyUSB0'
BAUD_RATE = 115200  # Adjust as needed

try:
    ser = serial.Serial(SERIAL_PORT, BAUD_RATE, timeout=1)
except serial.SerialException:
    ser = None
    print("Could not open serial port")

    def on_key(event):
        if event.keysym == 'Up':
            lift_action(1)      # Lift up
        elif event.keysym == 'Down':
            lift_action(0)      # Lower
        elif event.keysym == 'Left':
            grip_action(1)      # Grip
        elif event.keysym == 'Right':
            grip_action(0)      # Release

    root.bind('<Up>', on_key)
    root.bind('<Down>', on_key)
    root.bind('<Left>', on_key)
    root.bind('<Right>', on_key)

def send_command(cmd):
    if ser:
        print("Sending:", cmd)
        ser.write((cmd + '\n').encode())

def grip_action(state):
    send_command(f"grip={state}")

def lift_action(state):
    send_command(f"lift={state}")

def vacuum_action(state):
    send_command(f"vacu={state}")

def fork_send():
    value = fork_entry.get()
    try:
        val = int(value)
        send_command(f"fork={val}")
    except ValueError:
        print("Invalid fork value")

# GUI Setup
root = tk.Tk()
root.title("End Effector Control")

# Gripper Controls
ttk.Label(root, text="Top Gripper").grid(row=0, column=0, pady=5)
ttk.Button(root, text="Grip", command=lambda: grip_action(1)).grid(row=1, column=0)
ttk.Button(root, text="Release", command=lambda: grip_action(0)).grid(row=1, column=1)
ttk.Button(root, text="Disable", command=lambda: grip_action(2)).grid(row=1, column=2)

# Lifter Controls
ttk.Label(root, text="Lifter").grid(row=2, column=0, pady=5)
ttk.Button(root, text="Lift", command=lambda: lift_action(1)).grid(row=3, column=0)
ttk.Button(root, text="Lower", command=lambda: lift_action(0)).grid(row=3, column=1)
ttk.Button(root, text="Disable", command=lambda: lift_action(2)).grid(row=3, column=2)

# Vacuum Controls
ttk.Label(root, text="Vacuum").grid(row=4, column=0, pady=5)
ttk.Button(root, text="Enable", command=lambda: vacuum_action(1)).grid(row=5, column=0)
ttk.Button(root, text="Disable", command=lambda: vacuum_action(0)).grid(row=5, column=1)

# Fork Control
ttk.Label(root, text="Fork (cm)").grid(row=6, column=0, pady=5)
fork_entry = ttk.Entry(root)
fork_entry.grid(row=6, column=1)
ttk.Button(root, text="Send", command=fork_send).grid(row=6, column=2)

root.mainloop()

# Close serial when done
if ser:
    ser.close()

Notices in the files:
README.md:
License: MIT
